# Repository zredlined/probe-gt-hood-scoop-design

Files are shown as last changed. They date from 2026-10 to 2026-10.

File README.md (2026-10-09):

# Probe GT hood scoop — #42

A bolt-on, 3D-printed fresh-air hood scoop for the 4OGS Ford Probe GT race car. It sits over a 199 x 75 mm opening cut in the hood ahead of the cone filter, feeds outside air down through a lined throat, and a short flap under the hood turns that air toward the filter. Black ASA, purple accents, 4OGS wordmark inlaid on the roof. Every part prints without supports.

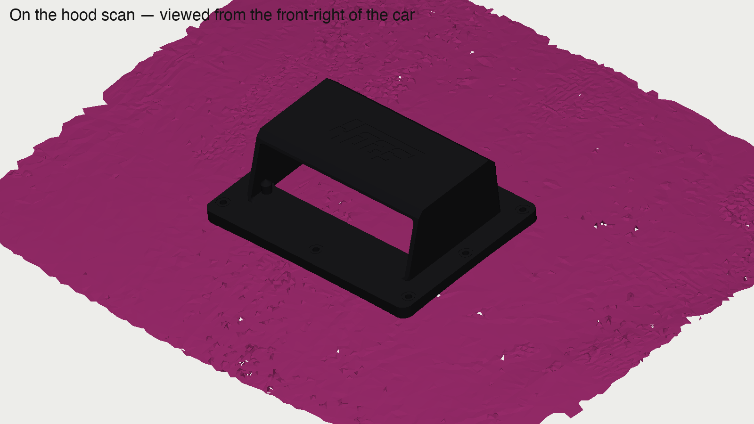
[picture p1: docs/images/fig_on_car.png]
On the hood


**Status: prototype, waiting for on-car checks.** The opening position, the hood's double-skin depth and the cone position all come from a 3D scan and a nozzle test, not from a tape measure. The first job is to print the template and confirm them. See the [build guide](docs/BUILD_GUIDE.md).

## What's here

| Folder | Contents |
|---|---|
| [`docs/BUILD_GUIDE.md`](docs/BUILD_GUIDE.md) | Step-by-step instructions with pictures. Start here. |
| [`docs/BOM.md`](docs/BOM.md) | Parts, hardware and filament. Only four things to buy. |
| [`docs/DESIGN.md`](docs/DESIGN.md) | How the design works, the coordinate frame, every parameter. |
| [`docs/DECISIONS.md`](docs/DECISIONS.md) | Why it is the way it is, newest first. |
| [`validation/`](validation/README.md) | What was checked against the scan and how the parts print. |
| [`stl/`](stl) | Printable parts, ready to slice. Local frame, millimetres. |
| [`step/`](step) | STEP export of the whole system for other CAD. |
| [`cad/`](cad) | Onshape FeatureScript (design master), the Python mirror that rebuilds the STLs without Onshape, and the validation and figure scripts. |
| [`reference/`](reference) | The scan meshes, the photos and the original design brief this was built from. |

## Parts at a glance

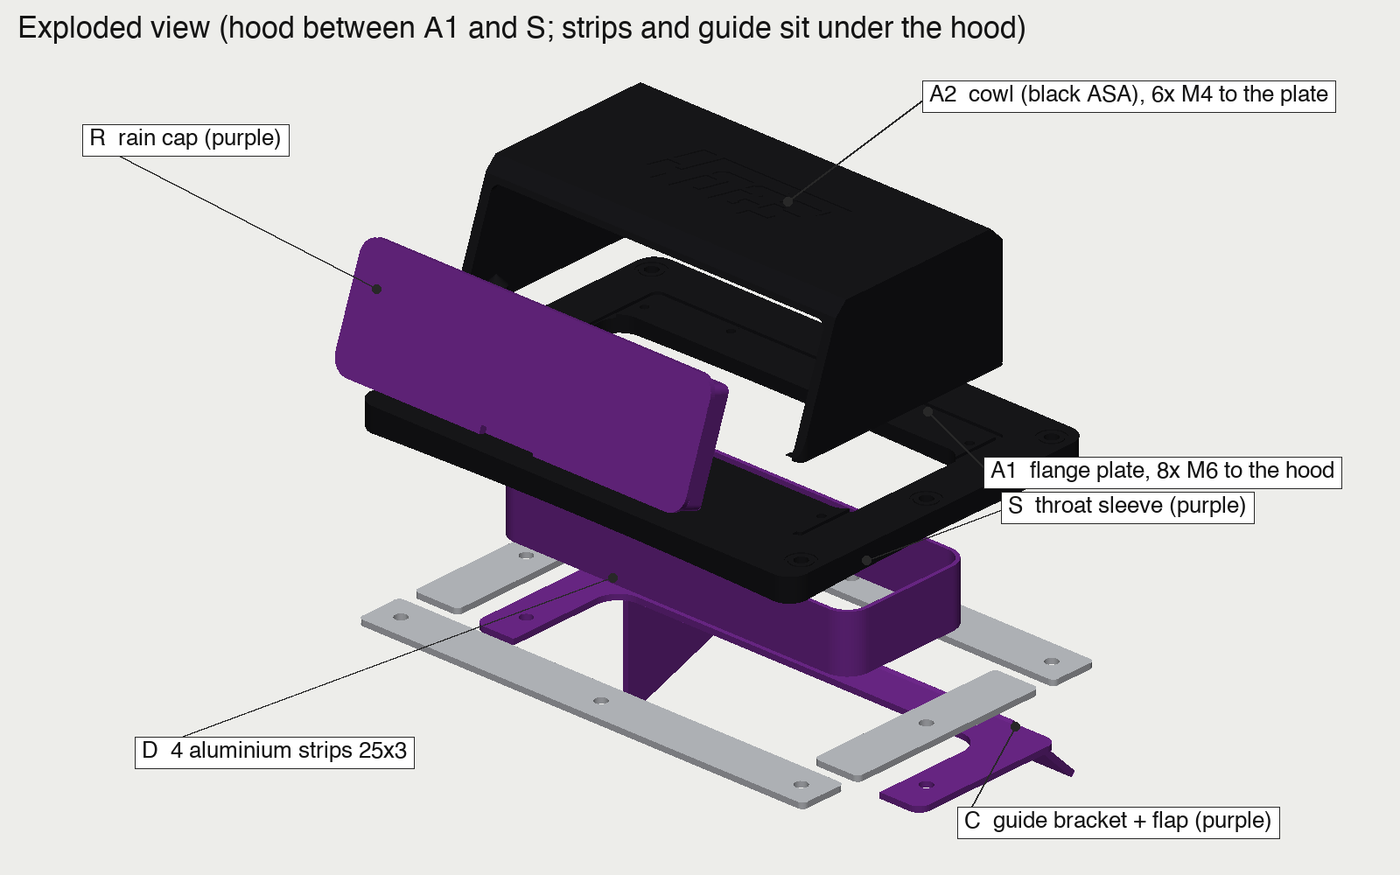
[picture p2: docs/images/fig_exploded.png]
Exploded


| Part | Material | Print | What it does |
|---|---|---|---|
| T  template | PLA | flat | Transfers the opening and the 8 bolt holes to the hood. Print this first. |
| A1 flange plate | black ASA | top face down | Matches the hood curve, carries the 8 M6 bolts, locates the cowl. |
| A2 cowl | black ASA (+ purple logo) | roof down | The slab with the raked mouth. Screws to the plate on the bench with 6 M4. |
| S  throat sleeve | purple ASA | standing | Lines the cut through both hood skins. |
| R  rain cap | purple ASA | flange down | Snap-in blank for rain or storage. |
| C  guide | purple ASA | bracket down | U-bracket plus 45° flap under the hood, aims air at the cone. |
| D  strips | 25 x 3 aluminium flat bar | cut and drill | Load-spreading backing for the 8 bolts. |

Hardware: 8 x M6x50, 6 x M4 self-tapping, nylocs, washers, Ø10 tube for limiters and spacers, 2 mm foam gasket tape.

## CAD

Design master: [Onshape document](https://cad.onshape.com/documents/b03b5bf08a93c5df66f722d9/w/0932d1534808bff872171f8f) (custom feature "Probe hood scoop system" in the "Probe scoop FeatureScript" tab; every dimension is a parameter). The scan meshes are in the same document in the scan frame, and the assembly "Scoop on car" shows the scoop on the hood.

To rebuild the STLs without Onshape:

```bash
pip install numpy trimesh shapely manifold3d networkx
python3 cad/local_build.py                      # writes stl/
python3 cad/local_build.py --set roofTop=76     # any parameter from DESIGN.md
```

The mirror was checked against the Onshape export of the same parameters: identical to within 0.13 mm.

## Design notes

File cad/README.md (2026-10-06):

# CAD sources

**Design master:** `scoop.fs`, an Onshape FeatureScript custom feature ("Probe hood scoop system"). It lives in the Onshape document's "Probe scoop FeatureScript" tab and is inserted into the Part Studio "Scoop system (placed on scan site)"; the "Scoop FLAT" studio holds the same feature laid flat for export. `scoop.fs` is generated by `gen_fs.py` (which injects the fitted hood-site frame from `site_fit.json`); edit the generator, not the .fs.

**Local mirror:** `local_build.py` rebuilds every printable STL from the same parameters without Onshape (numpy, trimesh, shapely, manifold3d, networkx). Verified against the Onshape export of the same parameters to 0.13 mm. Use it when the Onshape API quota is exhausted or when you just want parts.

```bash
pip install numpy trimesh shapely manifold3d networkx scipy matplotlib pillow rtree
python3 cad/local_build.py                       # -> stl/
python3 cad/validate.py                          # -> validation/ (needs reference/scan)
python3 cad/make_figures.py stl docs/images      # -> figures for the docs
```

**Onshape automation** (needs `ONSHAPE_ACCESS_KEY` / `ONSHAPE_SECRET_KEY` in the environment; every call counts against the account's API quota):
- `push_scoop.py '{"roofTop": 76}'` regenerates `scoop.fs`, pushes it, re-inserts the feature with all parameters (JSON overrides optional) and prints regeneration status.
- `assemble_export.py` rebuilds the "Scoop on car" assembly from the scan meshes plus the design studio, refreshes the flat studio, and exports STL/STEP.
- `mesh_scale.fs` is the tiny feature used to fix STL imports that Onshape read in metres.
- `os_api.py` holds the document IDs and auth helpers; `onshape_state.json` the element IDs created so far.

**Scan analysis:** `site_fit.py` fits the hood curvature at the opening site from `reference/scan/02_hood_outer_mm.stl` and writes `site_fit.json`. `raster.py` is a small z-buffer renderer used by the figure and check scripts.

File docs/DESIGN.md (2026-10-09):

# Design notes

## Intent
A supplemental fresh-air feed, not a sealed cold-air intake. The mouth faces forward on the hood's downslope, 74 mm up, well clear of the boundary layer. It captures far more air than the engine draws, so most of it spills into the bay and keeps the area around the cone filter slightly pressurised with outside air. A sealed airbox can bolt to the same opening and hole pattern later; the throat and bolt pattern were sized for that.

## Coordinate frame
Everything in the STLs is in a local frame on the hood at the opening centre O:
- **x** across the car, positive toward your right when standing at the bumper facing the car,
- **y** rearward toward the windshield,
- **z** out of the hood, zero at the outer skin surface at O. The plate underside follows the measured hood curvature (a quadratic fitted to the scan: 8.8° downslope toward the front, about 5 mm of sag at the plate corners).

In the scan's frame O is at about X 110, Y −340, Z 104. That came from the emissions-label neighbourhood the owner tested with a vacuum nozzle, not from a measurement, which is why the template exists.

## Parts and how they go together
Exploded

- **A1 flange plate**: 244 x 181 x 8, hood-matched underside, flat top. Eight Ø6.5 bolt holes with 0.6 mm debossed rings, a 1.5 mm seat for the sleeve, a 3 x 1.5 mm groove for the cowl tongue, six Ø4.3 countersunk holes for the cowl screws. Prints top-face-down with no supports.
- **A2 cowl**: 196 x 125 slab, roof at 74, mouth face raked back 20°, 4 mm brow chamfer, 10 mm tail chamfer, 4 mm corner radii. Mouth 186 x 55.5 (103 cm²) with a 2.5 mm inner lip radius. A 2.6 mm tongue on the skirt drops into the plate groove; six Ø10 bosses inside the skirt take M4 self-tapping screws (or captive M4 nylocs with `captiveNuts`). 4OGS wordmark debossed 0.6 mm on the roof for an AMS inlay. Prints roof-down with no supports.
- **S throat sleeve**: 199 x 75 outside, 2 mm wall, lines the cut through both skins so the cavity stays dry and the edges are hidden. Pushed up from below into the plate seat, sealed with RTV.
- **R rain cap**: flange matching the raked face, hollow 15 mm plug with 0.3 mm clearance, two 0.6 mm snap bumps, finger notch that doubles as a drain.
- **C guide**: U-bracket (two arms plus a rear bar) clamped under the side strips by the two middle bolts, with a 200 wide flap at 45° reaching 50 mm and a 55 mm inboard cheek that pushes air outboard toward the cone. Provisional until the clay test; reach, angle and cheek are parameters.
- **B bezel (optional)**: 5 mm purple frame flush in a recess on the raked face. Off by default; the AMS logo is the accent instead.
- **D strips**: four pieces of 25 x 3 aluminium flat bar under the inner panel. Two across (front and rear rows, 3 holes) and two short (middle bolts).
- **Fasteners**: 8 x M6x50 head-down, steel limiter tubes through the plate, steel spacer tubes across the inter-skin gap passing through Ø10.5 holes in the inner panel. The clamp path is head → strip → tube → outer skin → gasket → plate → nut, so no plastic carries preload and the inner panel is not pulled toward the outer skin. 6 x M4 join the cowl to the plate on the bench.

## Parameters
All in the Onshape feature and in `cad/local_build.py` (same names, mm).

| Group | Parameter | Default | Meaning |
|---|---|---|---|
| Opening | cutW, cutL, cutR | 195, 71, 10 | clear throat; hood cut = this + 2 x sleeveWall |
| | sleeveWall | 2 | |
| Hood stack | skinT, innerGap, innerT, gasketT | 0.8, 21, 0.8, 1.5 | **measure** innerGap at the pilot holes |
| Plate | baseW, baseFront, baseRear, baseR, baseT | 244, 97, 84, 10, 8 | |
| Cowl | bodyW, bodyFront, bodyRear, roofTop, wall, bodyR | 196, 65, 60, 74, 3, 4 | |
| | chamferF, chamferR, rakeDeg | 4, 10, 20 | |
| Mouth | mouthW, mouthR, lipR, bezelW | 186, 4, 2.5, 5 | mouth height = roofTop − chamferF − bezelW − gasketT − baseT (bezelW is the lintel band whether or not the bezel is built) |
| Cowl screws | bossD, bossH, screwPilot, screwClear, captiveNuts, nutAF, nutH | 10, 9, 3.4, 4.3, off, 7.2, 5.2 | six bosses at x ±91 y ±45 and x ±50 y 53 |
| Bolts | boltX, boltYF, boltYM, boltYR | 112, 80, −4, 72 | rows at y = −80, −4, +72; x = ±112 plus centre front/rear |
| | holeD, boltL, backingT | 6.5, 50, 3 | |
| Guide | guideW, guideReach, guideAngle, cheekH, guideT | 200, 50, 45, 55, 3 | physical-fit parameters |

## Design language
Teenage Engineering slab with a 90s scoop stance: flat top, crisp small chamfers, uniform radii, a raked mouth, exposed fasteners on a regular pitch, black body with a purple inlaid wordmark and purple functional parts. The car's livery is light blue and black with purple panels, hence purple.

## What is not proven
No CFD, no load test, no hood-closing sweep simulation. The scan's hood-underside registration is provisional (median 4 mm lateral, local conflicts) and the cone is not in the scan. The build guide's Round 1 exists to replace those assumptions with measurements. See [DECISIONS.md](DECISIONS.md) for why things are the way they are.

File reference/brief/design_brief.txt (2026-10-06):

ONSHAPE MCP BUILD PROMPT — PROBE HOOD SCOOP + BROAD AIR GUIDE
Revision 2026-10-05. Supersedes the MAX2509-specific handoff and earlier intake proposals.

TASK AND INTENT
Build actual editable parametric CAD in Onshape using your available MCP tools: an outside hood scoop, bolted mounting system, and removable broad air guide below the hood, delivering outside air toward the existing cone filter beside the battery. The owner may add shielding or an airbox later. The current configuration is an open fresh-air feed, with no promise that the cone will ingest only cold air.

IMPORTANT LATEST DECISION
DO NOT require a RIDGID nozzle, vacuum-hose connection, or 2.5-inch round restriction. The owner held a RIDGID MAX2509 under the hood and closed it to find a workable LOCATION and mouth FOOTPRINT. Preserve that packaging evidence; replace the nozzle with a broad printed guide. Its measured outside mouth was 195.2625 x 71.4375 mm. We deliberately adopt an approximately matching hood opening, now independent of the nozzle's unmeasured inside dimensions. Do not reproduce a vacuum nozzle or its snap fit.

PLACEMENT SOURCE OF TRUTH
The owner's attached underside screenshot contains a small white rectangle in an exposed light-colored rectangular region. Owner's clarification: stand facing the car and look at the underside of the raised hood; the box is just to the viewer's right, roughly aligned with the sticker visible in the scans. The physical nozzle test at that location allowed the hood to close. Treat that as the preferred location and approximate footprint, not as a calibrated global coordinate.
Do not move the opening elsewhere simply to fit the old concept. Do not reuse previous global X295/Y-70 or a 200 x 160 opening. Preserve the owner's viewing convention; underside and top views must not be silently mirrored. The screenshot does not establish an exact XYZ, orientation, or skin thickness. Do not invent millimeter measurements from its pixels or claim that gray scan regions prove absence of structure.

LOCAL DATUMS
Local O = center of the mouth footprint physically transferred to the hood at the tested location. Local X = long dimension across the car; local Y = rearward toward windshield; local Z = outward normal from hood. Mouth faces -Y, toward bumper. Confirm actual FRONT on the car; screen-up is not a vehicle datum. If the tested rectangle is yawed, expose opening_yaw separately from scoop_yaw and guide_yaw.
Before releasing a cutting drawing: place a 195 x 71 rounded-rectangle card in the tested position; trace the center and axes on masking tape. Check actual hood skins, reinforcement, bonded seams, and full hood closing sweep. Trial the complete flange/backing/nut/guide footprint, not just the hole. Record O relative to two identifiable physical hood features A and B (A-B, A-O, B-O and side of A-B, plus a third check dimension). Do not mix distances along curved sheet with projected CAD distances. After confirming the waste area, a small pilot hole inside that area can transfer the position to the outside; do not blindly drill through additional layers. Supply a photo or drawing identifying A and B. The sticker is a neighborhood identifier, not a precision datum.

PARAMETERS — MM, INITIAL DESIGN VALUES
cut_W = 195; cut_L = 71; cut_R = 10; center = O.
These are proposed cut dimensions based on the physically tested footprint, NOT measured existing hole dimensions. The guide mates to the new opening, so its external flange must be larger.
clear_mouth_W = 200; clear_mouth_H = 60; mouth_sill = 3 above local skin.
shell_wall = 3; main_flange_t = 5; flange_border = 20.
body_W = 210; body_front_Y = -65; body_rear_Y = +95.
base_W = 250; base_front_Y = -85; base_rear_Y = +115; total base footprint = 250 x 200.
Approximate scoop maximum height = 66 above local skin (3 sill + 60 clear + 3 roof), before curvature adaptation.
gasket_uncompressed_t = 2; compressed thickness per actual material.
metal_backing_t = 2 initial sheet-metal design value.
M5 fasteners; nominal clearance holes 5.5, finish-drilled.
All values are editable. Mark measured inputs separately from initial design assumptions.

UPPER SCOOP
Build a forward-facing hollow raised scoop. Smooth entrance lip, starting internal radius about 3 mm. Inner roof approximately 63 above local hood from Y=-65 through Y=+40, keeping the full downward passage over the aperture, whose aft edge is Y=+35.5. Smoothly close the tail by Y=+95; expose tail length as a parameter so it can be extended if room and printing allow. This short tail is a packaging choice, not an optimized low-drag aerodynamic profile. No rear-facing opening. No obstruction or decorative web across the throat.
The hood may form the floor outside the hole if the perimeter seal is continuous. Fit the flange to a smooth representation of the actual local outer hood curvature, or use a replaceable contoured adapter and gasket. Do not force a flat warped part down with bolt torque. Do not reuse the old hood curvature polynomial from a different location. Avoid converting the full scan mesh into thousands of CAD faces.

LOWER AIR GUIDE — DEFAULT OPEN CONFIGURATION
Use a removable broad chute/deflector connected to the underside mounting assembly. It moves with the hood. Its inlet follows the rounded 195 x 71 opening; use a radiused entry and no smaller hose neck. Start with two side cheeks and a smooth turning wall that redirects downward flow toward the exposed filter media. The outlet and underside remain open where needed for clearance, engine movement and drainage. Keep clear of the cone's solid end cap and avoid pressing against the filter.
Guide depth, guide reach, guide yaw, turn angle, outlet width, outlet height, and engine/filter clearances are physical-fit parameters, NOT dimensions inferred from the nozzle mouth. If the scan cannot establish them, create an adjustable/shallow fit-check version and a hinge/slot or interchangeable guide geometry, explicitly labeled provisional. Do not invent a full nozzle depth from the 71 mm mouth length.
Allow a 25-50 mm outlet-to-filter gap as a starting packaging target only where measured motion permits. Check all hood sweep positions and engine movement. Use broad radii and no unnecessary corrugated hose. Air can spill from this open guide; it is a practical supplemental cooling feed, not a pressure-sealed intake.

OPTIONAL LATER CLOSED CONFIGURATION
Provide an optional enclosed wide duct or airbox interface with the same hood opening and fastener pattern. Target a minimum clear cross-sectional area of 100-110 cm2; prefer about 120-135 cm2 where packaging allows. Evaluate areas in sections normal to the local flow path, not just plan-view widths. The rounded 195 x 71 cut is approximately 137.6 cm2; 200 x 60 mouth is 120 cm2 before mesh. If adding mesh, keep high open area and adjust dimensions so it does not become the smallest restrictive section; record open-area assumptions. Do not reduce the system to a 63.5 mm bore (~31.7 cm2). A later sealed airbox requires pressure/temperature testing; these geometry targets do not prove sufficient pressure recovery or flow.

HOOD FASTENING AND BACKING
Use eight M5 through-bolts, metal washers/clamp strips, metal compression limiters, positive locking nuts suitable for actual temperature, and a conforming metal underside load-spreading frame or strips. Initial local hole centers:
(-115,-75), (+115,-75), (-115,0), (+115,0), (-115,+105), (+115,+105), (0,-75), (0,+105).
Positions are parameters, to be moved if ribs/tool clearance require. Keep appropriate edge distance and distributed retention. Initial nominal hole-center distance from outer flange edge is 10 mm. Show washer diameters and tool-access envelopes. Put mounting bolts outside the airflow chamber.
Stack: bolt head -> metal washer/clamp strip -> printed flange with compression limiter -> weather gasket -> hood sheet -> metal backing -> washer -> locking nut.
A compression limiter must bear on metal across the relevant compressible stack; a sleeve floating inside plastic does not solve creep. Derive sleeve and bolt lengths from measured installed stack and specified gasket compression. Do not assign a generic tightening torque to crush thin sheet or plastic. Do not pull two separated hood skins together with bolt preload: move the hole or provide fitted spacers across a measured gap. Do not drill/cut reinforcement without a separate assessment; prefer keeping the owner's hole location and adapting flange/backing details.
All primary scoop retention must be through-bolted and metal-backed. No reliance on self-tappers, adhesive tape, printed screw threads, or heat-set inserts alone. The lower guide attaches independently to metal-backed captive hardware and can be removed without dismantling the upper scoop. Keep retention hardware captive or outside the airflow; nothing loose above the cone. Provide access for assembly and maintenance.

HEAT, PRINTING, WATER
ASA is a candidate for the exterior scoop, subject to the exact filament datasheet, actual surface temperature and print quality. Do not treat a published softening point as allowable sustained clamped temperature. Under-hood guide material needs its own heat assessment; allow a formed-metal guide using the same mounts if measured conditions exceed the printed material's capability. No unqualified approval of PLA. Printed parts need generous fillets, local flange gussets, sufficient perimeters and solid fastener zones; specify actual slicer wall results. Check warping, support removal and the printer's usable build area for a 250 mm-wide flange. If splitting, use a mechanically supported joint away from critical throat/fastener regions, not a thin glued butt seam.
Include an installed-low-point drainage path away from filter and electrical parts; keep rain from being deliberately dumped onto the cone. Offer a removable broad splash deflector if needed, without choking flow. The scoop is not rain-proof. Preserve the proper engine air filter.

ONSHAPE WORKFLOW / DELIVERABLES
Build named, editable variables, sketches, surfaces and solids using the available MCP tools. Work on the prototype while unknowns stay explicit. Do not stop at a prose design plan.
1. A small fit-check template/flat ring FIRST, showing 195 x 71 opening, R10 corners, center/axes, flange and backing envelopes. Use it to transfer physical position and check mounting access before cutting or printing the entire scoop.
2. Parametric upper scoop, contour adapter if required, removable open lower guide, and optional future closed-duct interface in separate parts/configurations.
3. Metal backing and retainer parts, sleeves, washers and fasteners modeled separately; hardware BOM with lengths calculated from measured stack.
4. Full-size cut/drill template with FRONT, O, physical A/B datums, cut contour, hole centers, and a 100 mm calibration line. Label PRELIMINARY until actual placement, skins, mounting and swept clearances are verified. A planar projection is not automatically a developed pattern for a curved hood; state the method and verify on the car.
5. Dimensioned top/side/section and exploded assembly views. Explicit installed assembly order. STL/3MF for printable parts, STEP for CAD exchange, DXF for backing and templates.
6. Check regeneration, wall thickness, watertight printable solids, assembly/tool access, continuous upper seal, broad airflow path and hood/engine swept clearance. State which checks were actually performed. Do not claim CFD, tested strength, exact scan placement, successful tool operations or physical fit without evidence.
7. Supply a short physical commissioning plan: inspect retention and hot-soak deformation, verify hood latch/closing clearance, check rain drainage, and compare intake temperature under comparable driving. If a sealed box is later added, include intake pressure-drop measurement at high engine demand.

REFERENCE FILES INCLUDED IN THIS PACKAGE (paths relative to this prompt)
../02_scan_reference/01_engine_bay_mm.stl
../02_scan_reference/02_hood_outer_mm.stl
../02_scan_reference/03_hood_underside_PROVISIONAL_mm.stl
Import in mm at shared origin. Global +Y approximately rearward, +Z up. The underside alignment has unresolved conflicts; it does not certify rib/part clearances. The cone is absent from the scan. If files are unavailable to your session, request them; do not pretend to have read them. Use the attached marked screenshot and owner's physical test to resolve location. Do not let obsolete earlier placement parameters override the latest user instruction.

TECHNICAL BASIS / REFERENCES
Area checks above are elementary geometry, not a CFD simulation. At assumed 0.16 m3/s engine demand a hypothetical actual 63.5 mm-ID tube has ~50.5 m/s mean velocity, versus ~11.6 m/s through the proposed hood aperture; actual captured flow and losses are unknown. This motivates eliminating the narrow vacuum fitting, not a promised performance gain.
ASA material guidance: https://help.prusa3d.com/article/asa_1809
RIDGID model identification only: https://www.ridgid.com/us/en/max2509

PACKAGE PHOTO REFERENCES (relative to this prompt)
../03_photos/01_user_marked_hood_underside.png — latest owner-selected location, white rectangle.
../03_photos/02_engine_bay_with_cone_filter.png — installed intake/filter context, absent from scan.
The folder 02_scan_reference contains historical scan documentation. Its geometric caveats remain relevant; the current brief controls design intent.

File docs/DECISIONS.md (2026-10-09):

# Decisions

Why the design is the way it is. Newest first. Each entry is the decision, the reason, and what it replaced.

## 2026-10-08 — Rev H

**Two-piece body, joined on the bench.** A flange plate printed top-face-down and a cowl printed roof-down, both with zero supports. Six M4 screws go up through countersunk holes in the plate into bosses inside the cowl skirt, with a tongue-and-groove to locate them. Replaces the one-piece body, which needed a full ring of support under the flange at 60 mm and put support scars on the visible nut face. Also fixes a gap in the earlier two-piece attempt, which had no fastener between cowl and base. Self-tapping M4 is the default; a parameter switches the bosses to captive M4 nyloc pockets.

**Mouth face raked 20°.** The front face leans back instead of standing vertical. Less bluff, throws rain down rather than into the throat, and it is the most recognisable 90s scoop cue (WRX, Evo, GTi-R all had raked boxes). Roof raised 72 → 74 to keep the mouth above 100 cm² (now 186 x 55.5, 103 cm²).

**AMS for the logo, not the bezel.** The 4OGS deboss on the roof becomes a purple inlay with three filament swaps in the first layers, which costs almost nothing. A full-height purple bezel would swap on every layer and purge 150–300 g of filament for a 3 g feature, so the bezel is now an optional separate part, off by default.

**Scan meshes re-registered in Onshape.** The STL import had centred each mesh on the origin; the scoop therefore appeared displaced toward the middle of the hood in the assembly. The unit-fix feature now also moves each mesh back by its original bounding-box centre. The local renders and validation were never affected; they always used the raw scan files.

## 2026-10-06 — Rev F / G

**Bolts head-down, nylocs on top.** With nuts underneath, the bolt ends came within 2 mm of engine-bay structure at the front-right corner, where the scan shows only about 43 mm under the skin. Heads down removes 10 mm of under-hood protrusion.

**Guide clamped by the two middle bolts.** A U-bracket with the flap replaced a hanger ring with rivnuts, bosses and four M6x20. Removes four purchases and a tool; the guide comes off by loosening two nuts.

**Four pieces of 25 x 3 flat bar instead of a sheet frame.** Hardware-store material, hacksaw and drill.

**Cowl narrowed 210 → 196.** A 10 mm socket on the side nuts needed 8.5 mm of radius and had 7. Now 14 mm centre-to-wall.

**Spacer tubes through an oversize hole in the inner panel.** The hood is double-skinned at the site (about 21 mm, varying). The tube bears on a washer against the outer skin and the inner panel is never clamped, so the depth at each hole only changes a tube length.

## 2026-10-05 — Rev A to E

**Location.** The owner's nozzle-tested spot on the exposed label patch, not a position inferred from the scan. The scan was used to find the site (label colours), fit the hood curvature there, and check clearances.

**Hardware M6.** The brief said M5; the owner has M6x50 in quantity.

**Throat sleeve.** The hood cut grows to 199 x 75 so a 2 mm liner can run through both skins, keeping the cavity dry and hiding cut edges.

**Open fresh-air feed, not a sealed intake.** Per the brief. The throat and bolt pattern are sized so a sealed box can be added later on the same opening.

**Teenage Engineering slab, black with purple accents.** Flat roof, small chamfers, uniform radii, exposed fasteners on a regular pitch, debossed wordmark. Colours follow the car's livery.

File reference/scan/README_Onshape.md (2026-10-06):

# Probe engine bay and hood — Onshape reference, first pass

Import the STL files as **millimeters**. All share one coordinate system. Z points approximately up, Y approximately rearward and X across the car. The frame comes from the bay scan, not a surveyed vehicle centerline or ground plane. Keep the supplied origin and orientation; do not center or rotate individual meshes independently.

## Start with these files

- **01_engine_bay_mm.stl** — 250,000 triangles, about 12.5 MB. Engine bay with its captured surrounding panels.
- **02_hood_outer_mm.stl** — about 100,000 triangles, 5 MB. Isolated outer hood, positioned from the closed-hood exterior scan through overlapping bodywork.
- **03_hood_underside_PROVISIONAL_mm.stl** — about 150,000 triangles, 7.5 MB. Approximate closed-position underside. This placement has unresolved local conflicts and is not approved for tight clearance decisions.
- **04_combined_LAYOUT_ONLY_PROVISIONAL_mm.stl** — all three, about 500,000 triangles, 25 MB. One-file convenience reference. Includes the provisional underside. It is a concatenation of open mesh surfaces, not a welded or watertight solid; separate component names and convenient visibility controls are not guaranteed in an STL import.
- Matching **color PLY** files — for color inspection in CloudCompare or other mesh tools; use STL for this Onshape workflow.

These are reference meshes, not printable parts. Use them to locate and shape new parametric CAD parts. Scanned openings and missing coverage remain open. A missing surface does not establish free space.

## Onshape setup

1. Unzip the package. Create an Onshape document and import the three numbered individual STL files, choosing **millimeter** units. Leave any Y-up to Z-up reorientation off: these files are already approximately Z-up.
2. Keep the imports as separate references so the outer hood and underside can be hidden independently. If imports appear in separate Part Studios, use a design Part Studio with Derived references at **Base origin**, without additional placement. If the mesh selection is inconvenient in your import, the combined STL provides a one-file layout alternative.
3. Check scale against these approximate envelopes: engine-bay mesh 1630 × 1439 × 539 mm; isolated hood outer 1487 × 1389 × 114 mm. These are bounding boxes of the captured geometry, not nominal factory part dimensions.
4. Begin with the engine bay and outer hood. Enable the provisional underside only when reviewing its uncertainty. Model the vent and duct as normal CAD features, using local sections/reference sketches where needed. Avoid converting every mesh triangle into an individual CAD face.
5. Before fixing a close-fitting duct, validate the underside position with physical measurements or an additional scan that provides a stronger geometric connection. Check the front headlight notches, both rear corners, and several inner-reinforcement heights.

The exports were read back locally and checked. They have **not** been imported into the user's Onshape account during this task.

## What is established

The saved EXStar clouds were extracted with their normals and captured colors. Original EXStar projects were not changed. The hood-closed exterior and hood-open engine bay were aligned by a rigid, unit-scale geometry fit using common painted bodywork. No matching marker constellation was found between those projects; the underside has no saved marker set.

Five overlapping body regions were checked after fitting. Median nearest-point differences were about **0.54–1.05 mm**, with 95th-percentile differences **1.04–1.64 mm** among accepted local correspondences. These are agreement between scans, not certified physical accuracy. Checks use geometric correspondence and normal agreement; unmatched/uncaptured regions are excluded and counts are in the JSON report.

The outer hood was separated by identifying exterior surfaces absent from the hood-open scan and selecting the connected hood footprint. This is a scan-derived segmentation, not an exact factory trim boundary. Shared-body subtraction can trim a few millimeters near the panel gaps; small segmentation imperfections remain.

## What remains provisional

The underside was rigidly fitted using painted perimeter strips and the isolated outer-hood silhouette, including the headlight notches and curved rear edge. No scaling, nonrigid warping, or forced surface fusion was used. A folded underside edge is not the same physical surface as the top skin.

The final fit used 1,691 perimeter samples after excluding 247 likely background/nonmatching samples from the fit. Median lateral edge disagreement is **4.41 mm**, and the 95th percentile is **12.32 mm**. Median absolute vertical edge disagreement is **1.27 mm**, with a 95th percentile of **3.98 mm**. These fitted-edge statistics do not establish interior accuracy.

A separate raw-point height check found unresolved intersections: among interior underside samples with nearby outer-skin support, about **6.8% lie more than 2 mm above the outer skin**, and **2.9% more than 5 mm above**. This diagnostic includes all captured underside geometry in the tested footprint; it does not establish the cause. The underside is therefore useful for reviewing the rough layout, but **do not trust it as a collision envelope yet**. The cross-section image shows the mismatch. A tight duct design should wait for these conflicts to be reconciled.

Three disconnected wiper/background fragments were removed from the Onshape underside mesh after component inspection. The full extracted cloud and detailed meshes preserve them for review. Other small captured parts were retained where possible.

## Mesh processing and validation

CloudCompare performed spatial subsampling at 2 mm for the bay/exterior and 1.5 mm for the underside. Open3D performed ball-pivoting reconstruction and quadratic simplification. No global watertight reconstruction, blanket hole filling, or surface smoothing was used.

The final CAD copies total about 500,000 triangles. Bidirectional sampled comparisons against the detailed reconstructed meshes give 95th-percentile simplification differences below **0.30 mm** for all three. This isolates the extra change caused by simplification: it does not include scan error, alignment error, missing coverage, or reconstruction error. Larger local maxima are recorded in the report.

The full native-color clouds, aligned clouds, detailed meshes, transform matrices, scripts and logs remain in the parent work folder. The separate Blender review file preserves three named objects at the supplied positions. The exploded illustration temporarily offsets the hood layers for visibility; the STL files and saved Blender objects have no exploded offset.

## Official Onshape references

- [Importing files and STL units](https://cad.onshape.com/help/Content/Document/importing_files.htm)
- [Mixed modeling with mesh references](https://cad.onshape.com/help/Content/PartStudio/mixed_modeling.htm)
- [Derived and base-origin placement](https://cad.onshape.com/help/Content/PartStudio/derived.htm)

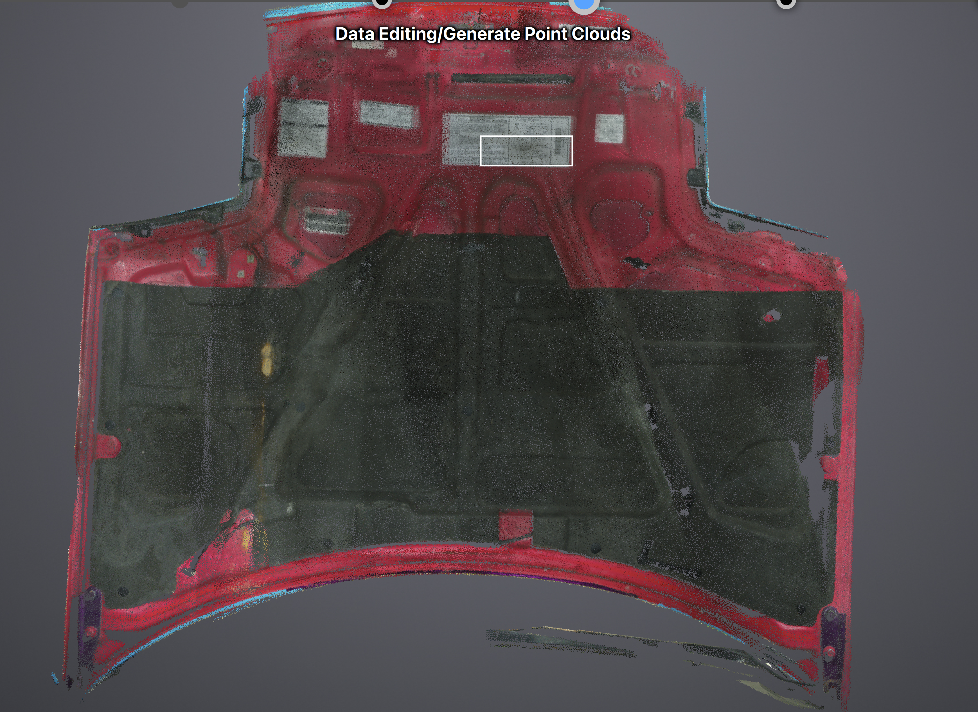
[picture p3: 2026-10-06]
reference/photos/01_user_marked_hood_underside.png

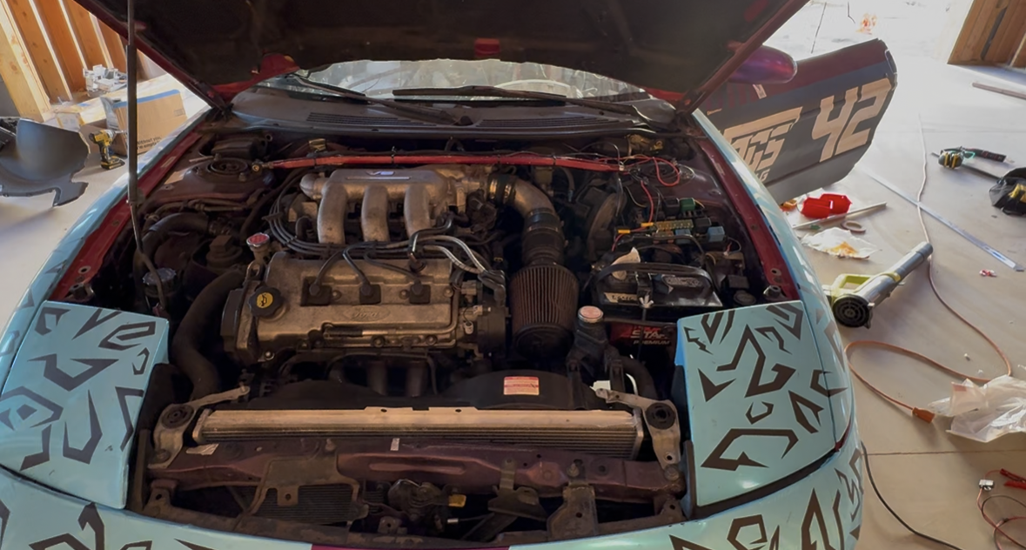
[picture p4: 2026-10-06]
reference/photos/02_engine_bay_with_cone_filter.png

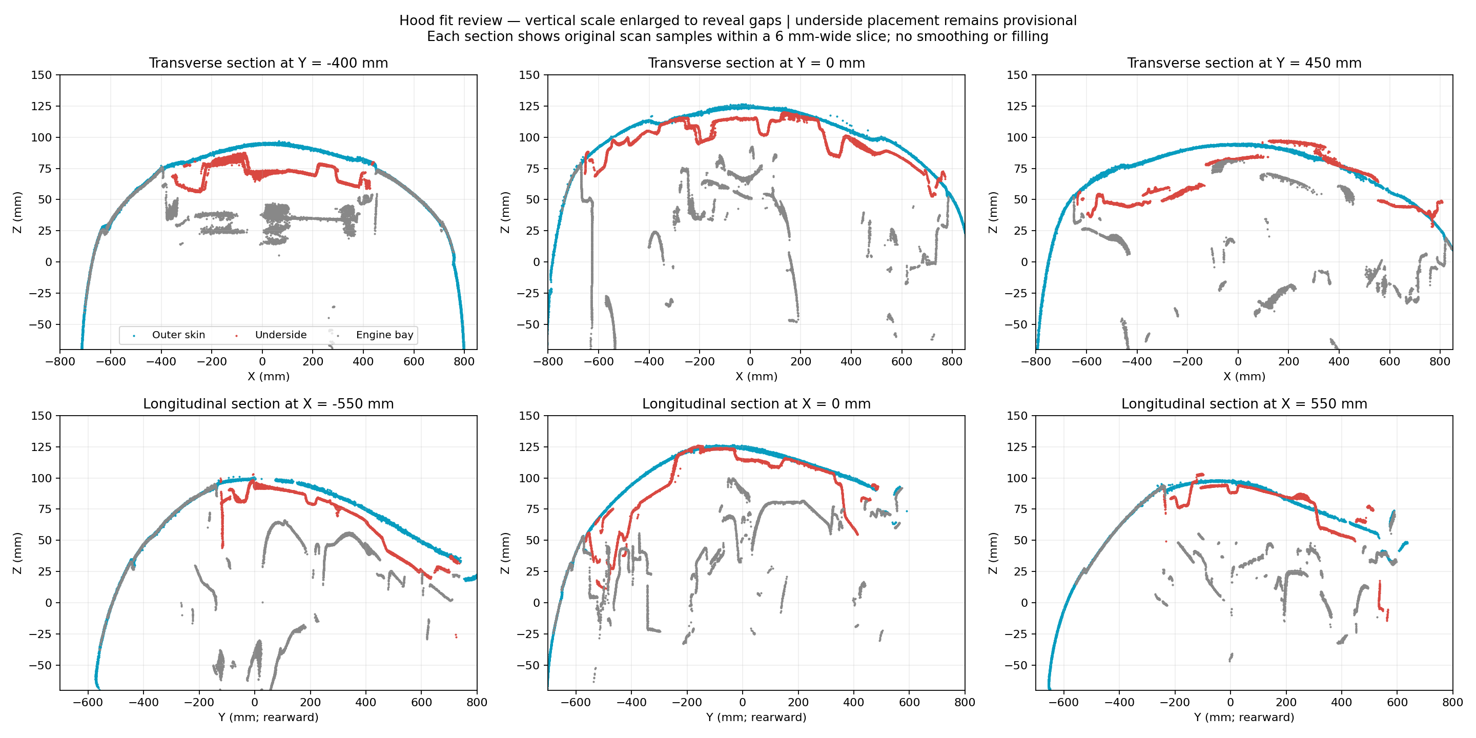
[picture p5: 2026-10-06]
reference/scan/05_raw_scan_sections.png

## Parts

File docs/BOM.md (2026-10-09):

# Bill of materials

Depths marked **measure** are confirmed in Round 1 of the build guide before anything is cut to length.

## Printed parts

| Part | File | Material | Orientation | Supports | Walls / infill | Filament |
|---|---|---|---|---|---|---|
| T  template | `stl/T_fit_check_template.stl` | PLA | flat | none | 2 / 15 % | ~40 g |
| A1 flange plate | `stl/A1_flange_plate.stl` | ASA, black | top face down (curved side up) | none | 4 / 15 % | ~150 g |
| A2 cowl | `stl/A2_cowl.stl` | ASA, black (+ purple for the logo, see below) | roof down | none | 4 / 30 % | ~95 g |
| S  throat sleeve | `stl/S_throat_sleeve.stl` | ASA, purple | standing | none | 3 / any | ~21 g |
| R  rain cap | `stl/R_rain_cap.stl` | ASA, purple | flange down, plug up | none | 3 / 20 % | ~55 g |
| C  guide | `stl/C_guide_flap.stl` | ASA, purple | bracket down | none (45° flap) | 4 / 30 % | ~41 g |
| B  bezel (optional) | build with `--set buildBezel=1` | ASA, purple | on its back | none | 3 / 100 % | ~3 g |

Totals: black ASA about 245 g, purple ASA about 120 g, PLA about 40 g. Estimates, allow 25 %. Nothing needs supports.

**Logo inlay with the AMS:** the cowl prints roof-down, so the 0.6 mm 4OGS deboss is in layers 1–3. Assign those layers (or a modifier on the deboss) to purple. Three swaps total. Do not multi-colour anything taller; a full-height purple bezel would purge more filament than the whole part weighs.

### Why these materials
- **ASA** for every part on or under the hood. The skin reaches 70–90 °C in sun with a hot engine; ASA stays stiff to about 95 °C and does not chalk in UV. Door closed, nozzle 260–270 °C, bed 90–100 °C, aux fan off, part fan low, dry filament, glue stick on the textured plate, 5 mm brim on the plate.
- **PLA** for the template only (softens above ~55 °C).
- **PETG** is not recommended on the hood (softens 75–80 °C). Fine for a throwaway first-fit guide.
- If the guide droops after a hot run, print it again in PC or PA-CF from the same file.

## Hardware

| Item | Qty | Spec | Notes |
|---|---|---|---|
| M6 x 50 button head (ISO 7380) | 8 | 8.8 or stainless | On hand. Head goes under the strip, nyloc on top. |
| M6 nyloc nut | 8 | DIN 985 | On top of the plate. |
| M6 flat washer Ø12 | 16 | DIN 125 | 8 under the nuts, 8 between spacer tube and outer skin. |
| M4 x 16–20 self-tapping screw, countersunk | 6 | for plastic | On hand. Cowl to plate, fitted on the bench. (Or M4 x 16 machine screws with M4 nylocs in the bosses: build with `--set captiveNuts=1`.) |
| Aluminium flat bar 25 x 3 mm | 1 m | 6061 or 6082 | 2 x 249 mm with three Ø6.5 holes, 2 x 110 mm with one hole. |
| Tube Ø10 outside, 1.5 wall | 1 m | aluminium or steel | 8 limiters at **8.0 mm** (plate thickness), 8 spacers at the **measured** depth minus 2.4 mm. |
| Closed-cell foam tape 2 mm x 20–25 mm | 1.5 m | EPDM or neoprene, adhesive | Gasket loop under the plate and around the throat. |
| RTV silicone or seam sealer | 1 tube | black | Sleeve to inner panel. |
| Rust primer or touch-up paint | 1 | | Cut edges and holes. |
| M6 acorn nut | 8 | DIN 1587 | Optional. Covers the ~7 mm of thread above the nyloc; otherwise trim. |

New purchases: the flat bar, the tube, the foam tape, and nylocs if there are none in the bin.

## Tools
Drills 3, 6.5 and 10.5 mm (or a step drill), Ø24 hole saw or step drill for the corners, jigsaw with a fine metal blade or a nibbler, files, deburring tool, hacksaw or cut-off wheel, depth gauge or hooked wire plus ruler, masking tape, torque wrench to 6 N·m, 10 mm socket, 4 mm hex key, PH2 or T20 driver for the M4s.

## Bolt stack
Head below the strip, nut on top. From the bottom: button head 3.3 → strip 3 → spacer tube (measured, through a Ø10.5 hole in the inner panel) → washer 1.6 → outer skin 0.8 → gasket 1.5 compressed → plate 8 with a steel limiter tube inside → washer 1.6 → nyloc 6. At the scan's 21 mm gap that is 42.7 mm head-to-nut, leaving about 7 mm of M6x50 above the nut. If a measured depth exceeds about 32 mm, that hole needs an M6x60.

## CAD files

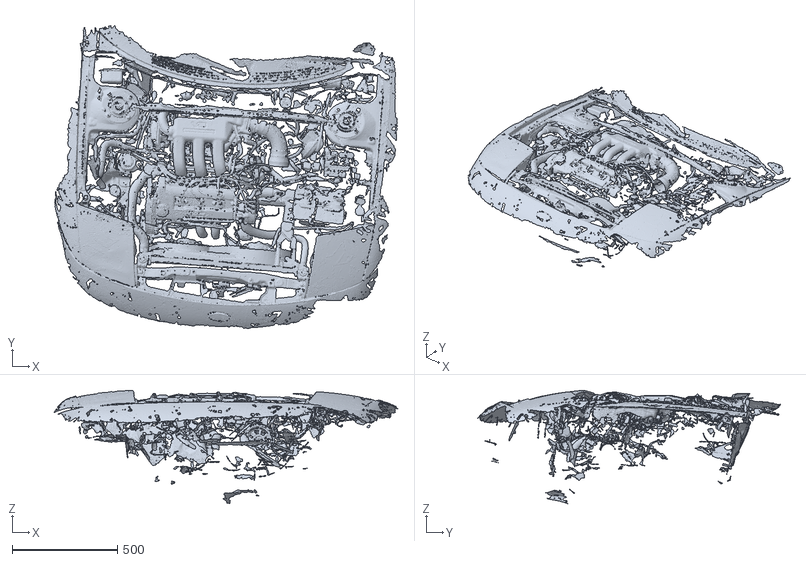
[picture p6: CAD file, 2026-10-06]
reference/scan/01_engine_bay_mm.stl
1630.3 x 1439.5 x 538.7

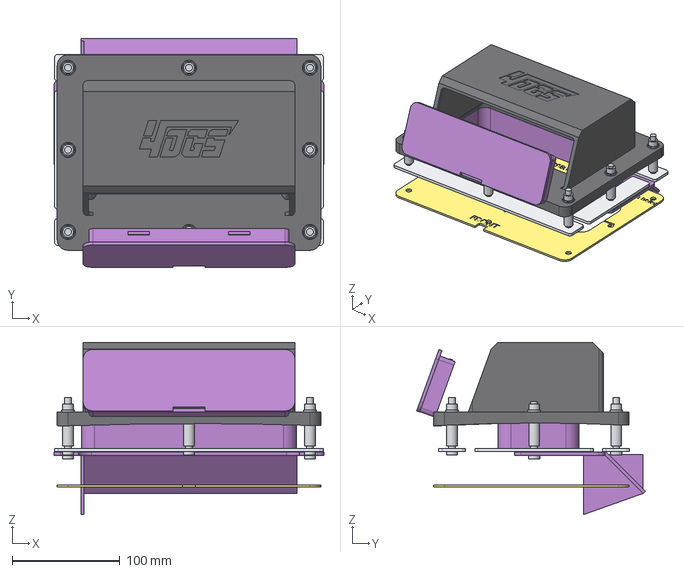
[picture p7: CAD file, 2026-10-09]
step/probe_hood_scoop_system.step
250.0 x 211.8 x 159.6 mm

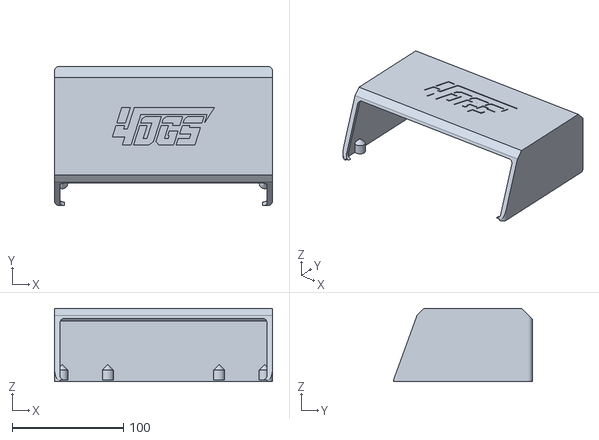
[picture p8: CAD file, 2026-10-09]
stl/A2_cowl.stl
196.0 x 125.0 x 66.0

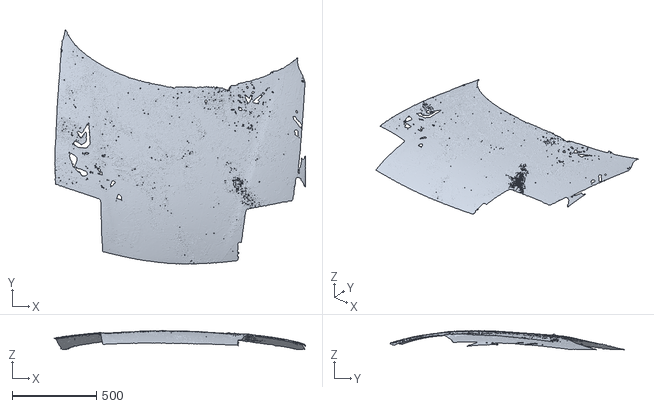
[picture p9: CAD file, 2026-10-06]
reference/scan/02_hood_outer_mm.stl
1487.4 x 1388.8 x 114.1

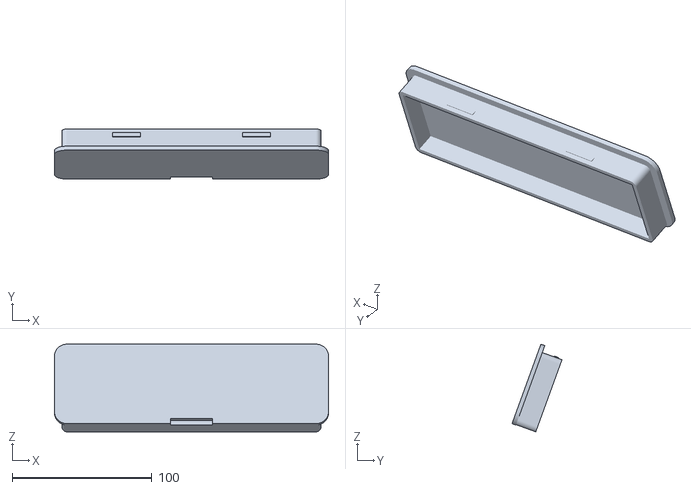
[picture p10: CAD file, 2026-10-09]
stl/R_rain_cap.stl
196.0 x 35.8 x 62.7

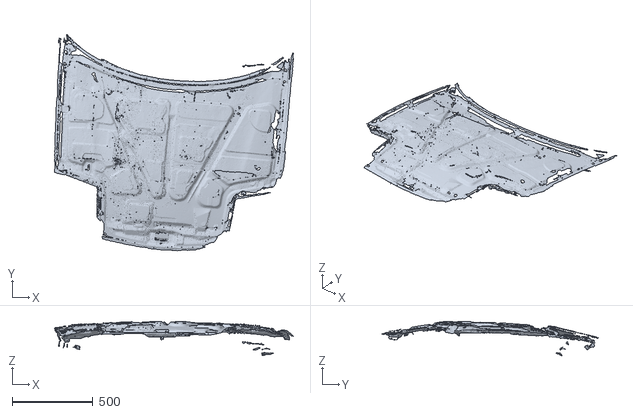
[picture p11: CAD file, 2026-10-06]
reference/scan/03_hood_underside_PROVISIONAL_mm.stl
1479.3 x 1340.9 x 212.5

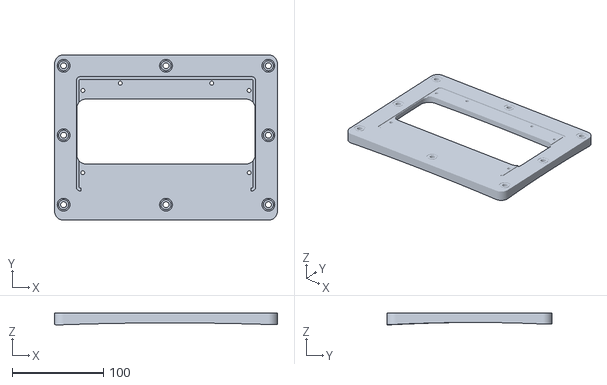
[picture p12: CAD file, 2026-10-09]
stl/A1_flange_plate.stl
244.0 x 181.0 x 12.8

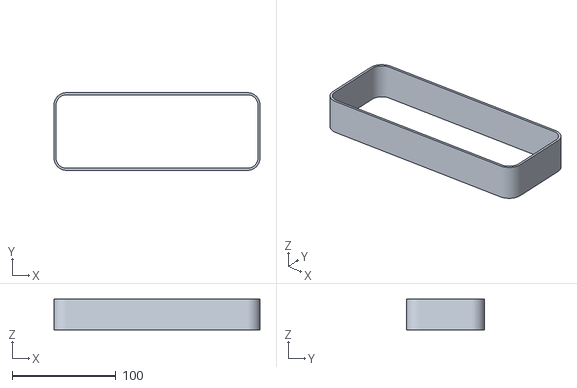
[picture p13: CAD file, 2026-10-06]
stl/S_throat_sleeve.stl
199.0 x 75.0 x 29.9

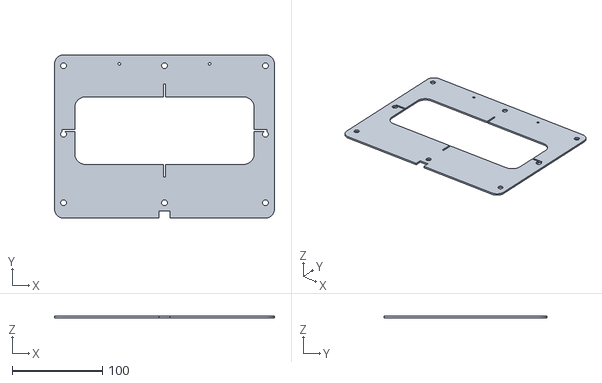
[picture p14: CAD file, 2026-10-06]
stl/T_fit_check_template.stl
244.0 x 181.0 x 2.00

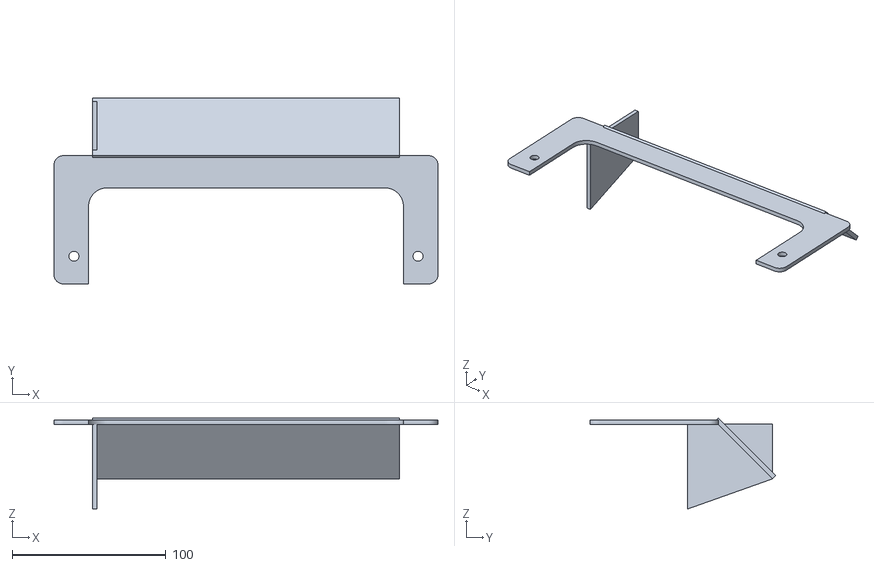
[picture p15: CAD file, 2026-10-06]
stl/C_guide_flap.stl
250.0 x 121.0 x 59.2

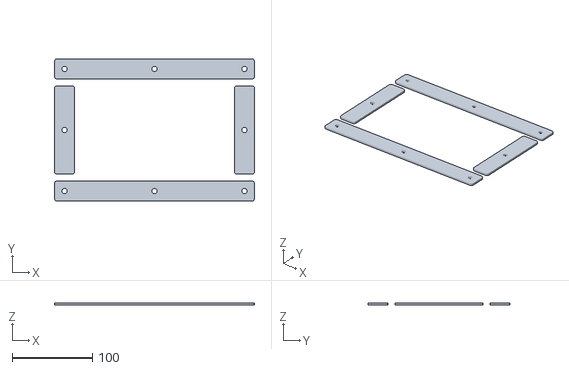
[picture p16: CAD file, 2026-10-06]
stl/D_backing_strips_reference.stl
249.0 x 177.0 x 3.00

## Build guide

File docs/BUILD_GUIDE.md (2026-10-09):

# Build guide

This is written for whoever is at the car. Everything is in millimetres. "Front" always means toward the bumper, and "right" means your right when you stand at the bumper facing the car.

There are two rounds. **Round 1** is the template and a few measurements. Send those back and the design gets updated (bolt lengths and tube lengths depend on them). **Round 2** is the actual cut and fit.

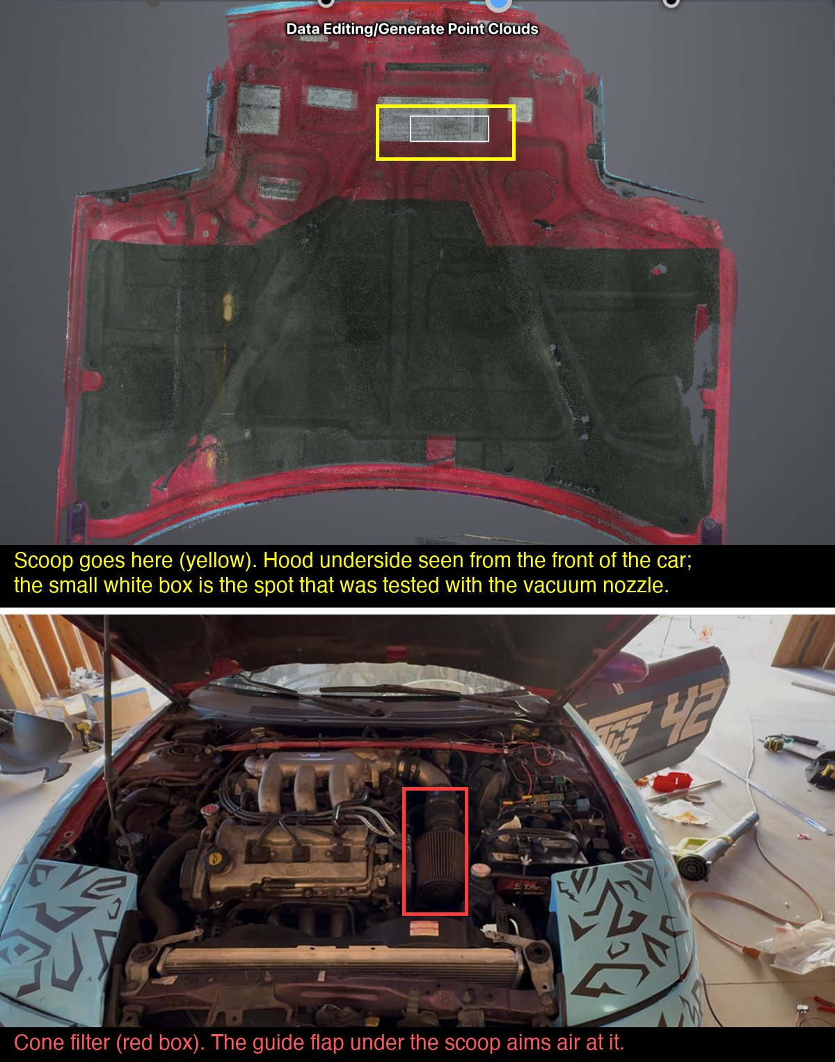
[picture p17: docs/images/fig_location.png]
Where it goes


---

## Round 1 — check the spot (an hour, no cutting)

### What you need
- The template, printed: `stl/T_fit_check_template.stl`, PLA, flat on the bed, 0.2 mm layers. Check it after printing: the two small holes near the back edge must be exactly 100 mm apart.
- Masking tape, a marker, a 3 mm drill, a depth gauge or a stiff piece of wire and a ruler, a phone for photos.

### 1. Put the template on the hood
Hood up. Hold the template against the **underside** of the hood on the bare metal patch with the emissions stickers, to the right of centre. The small triangle notch points to the **front** (bumper). Line the centre cross up with the spot that was tested with the vacuum nozzle.

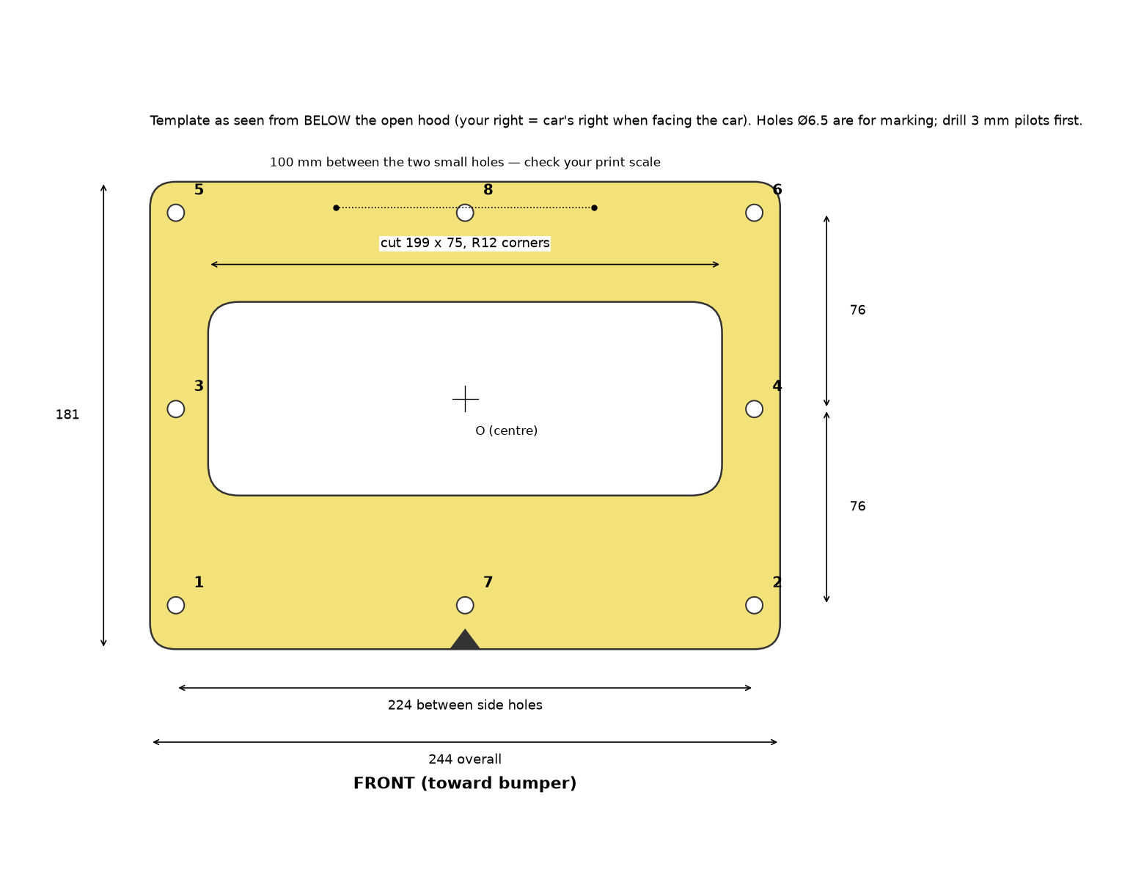
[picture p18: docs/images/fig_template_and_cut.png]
Template


Look for:
- The whole template lies on flat metal. No hole should land on a raised rib or on the black insulation pad. If one does, slide the template a little and tell us how far.
- Nothing above the template inside the engine bay would be hit by a box 70 mm tall sitting where the template is. If you have a 70 mm block, set it on the patch and close the hood slowly. It should close with room to spare.

Tape the template down. Mark through all 8 holes and draw around the inside of the big opening. Write the hole numbers next to the marks (they are on the drawing above).

### 2. Pick two landmarks
Pick two things on the hood underside that will not move, for example a weld nut and a rib corner. Call them A and B. Measure A to B, A to the template centre, and B to the template centre. Take a photo showing A, B and the template. This lets us put the template back in exactly the same place later.

### 3. Drill eight 3 mm pilot holes
Through each of the 8 marks, drill straight through the hood. You will go through two layers of metal: the inner panel and then the outer skin. Go slowly at the end so the drill does not wander on the paint.

### 4. Measure the depth at each hole
At each pilot hole, measure from the **top of the paint** down to the **underside of the inner panel**. A depth gauge, or a wire with a hook bent on the end, pushed through from the top and pulled back until it catches. Write all eight down with the hole numbers. The scan suggests they vary between about 12 and 38 mm; that is expected.

Also note the thickness of the outer skin if you can see it at a hole (probably about 0.8 mm).

### 5. Send back
- Photo of the taped template on the hood, with A and B visible.
- The A–B, A–centre, B–centre distances.
- The eight depths.
- Anything that looked wrong.

That is the end of Round 1. The design will be updated with the real depths, and the two bolts that might need to be longer get decided.

---

## Round 2 — cut, make, print, fit

### Parts to have ready
Everything in [BOM.md](BOM.md). Nothing needs supports. The plate prints top face down (the curved side ends up on top), the cowl roof down. ASA wants a closed printer door, a hot bed, and a brim on the plate. If you use the AMS, the logo in the first three layers of the cowl is where the purple goes.

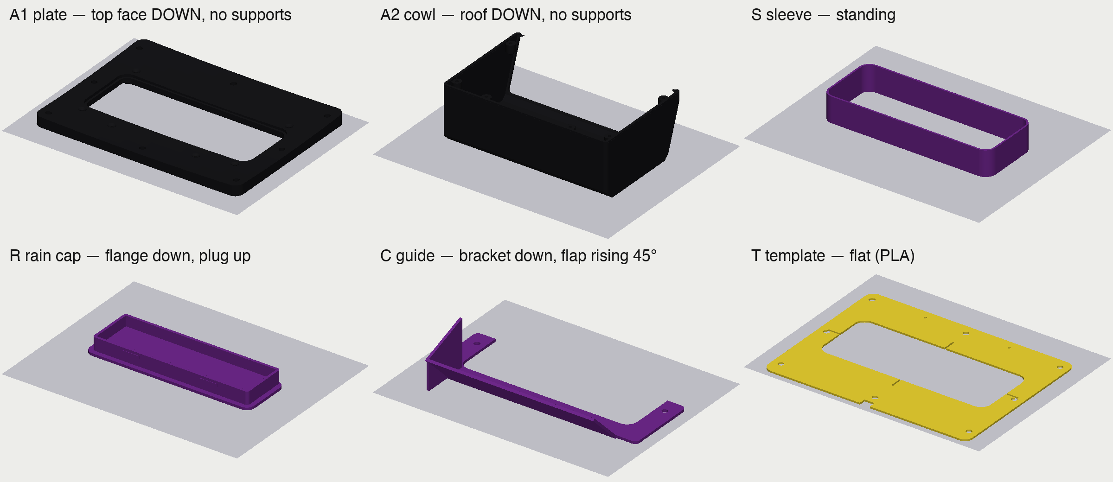
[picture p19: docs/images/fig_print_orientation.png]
Print orientations


### 6. Join the cowl to the plate (bench)
Set the plate on the bench **upside down**, curved side up. Drop the cowl onto it the right way round (logo reads from the front, raked mouth toward the FRONT notch side of the plate); the lip around the cowl's bottom edge sits in the groove in the plate. Hold them together and drive the six **M4 self-tapping screws** up through the countersunk holes in the plate into the bosses inside the cowl. Snug, not cranked; they only hold a plastic lid on. Turn the assembly over and check the cowl sits flush all round.

Exploded

### 7. Cut the opening
Mask the paint. From outside, drill a 3 mm hole at the template centre first and check the outline looks right against the hood from above. Then cut the outer skin to **199 x 75 mm with 12 mm radius corners**: a hole saw or step drill at the four corners, a jigsaw with a fine metal blade between them. Stay 1 mm inside the line and file to size. Cut the inner panel to the same size from below. Deburr everything and prime the bare metal.

### 8. Open the bolt holes
Outer skin: **6.5 mm**. Inner panel: **10.5 mm** (a step drill is easiest). The inner panel gets the bigger hole on purpose: a spacer tube passes through it and bears on the outer skin, so the inner panel is never squeezed.

### 9. Make the metal bits
Flat bar 25 x 3: two long pieces, 249 mm, each with three 6.5 mm holes. The easy way to mark them is to lay the template on the bar and mark through holes 1-7-2 for one strip and 5-8-6 for the other. Two short pieces, 110 mm, with one hole in the middle. Round the ends and deburr.

Tube Ø10: eight **limiters, 8.0 mm long** (they must all be the same length, square ends). Eight **spacers**, one per hole, each cut to that hole's measured depth minus 2.4 mm (that is minus the skin and a washer). Label them 1 to 8.

### 10. Bolt it on

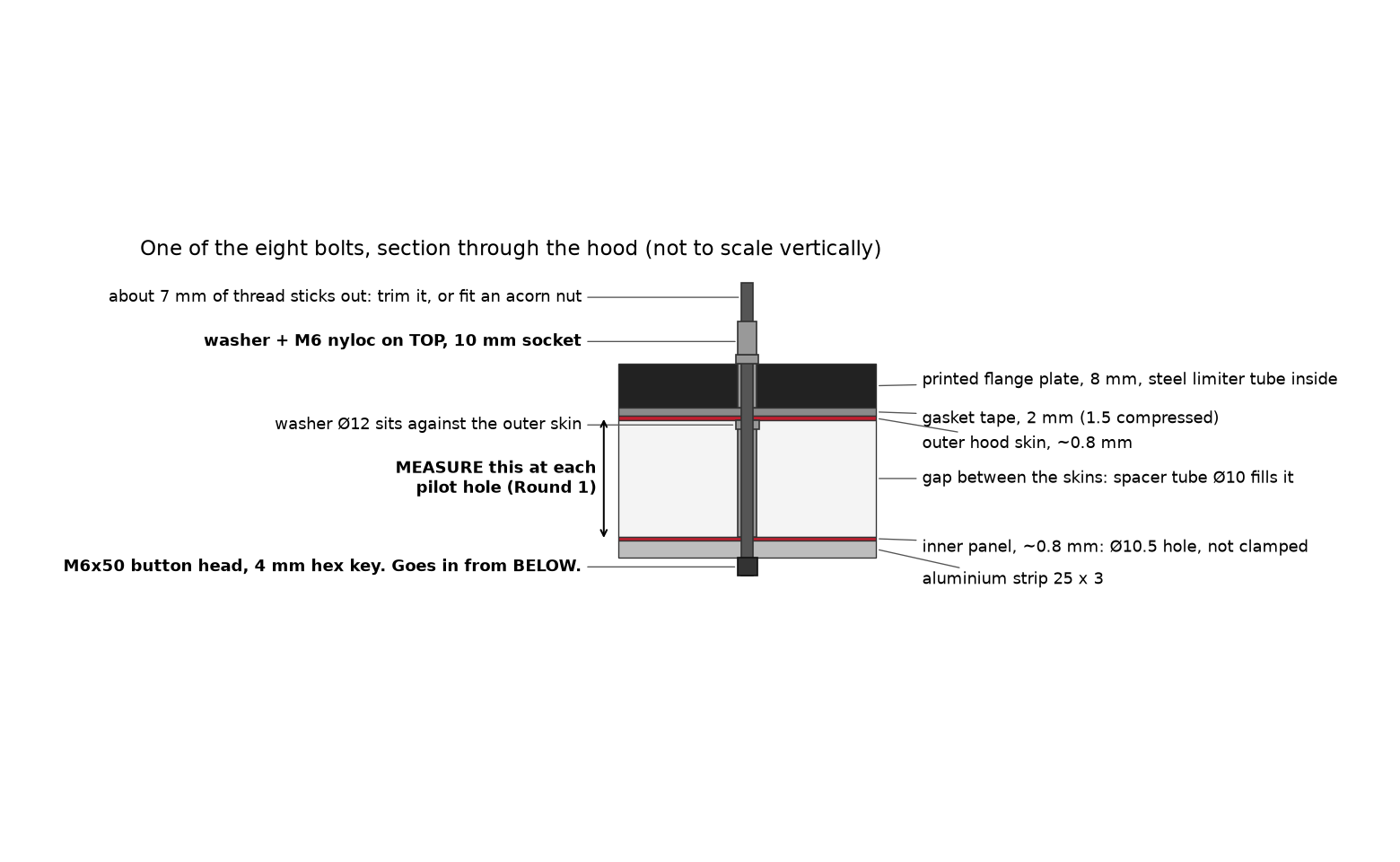
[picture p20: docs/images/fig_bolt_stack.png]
Bolt stack


1. Stick the foam gasket tape around the underside of the plate as one unbroken loop near the edge, and a second loop around the throat.
2. Push the eight limiter tubes into the plate holes. Set the assembly on the hood over the opening.
3. From below, for each hole: slide a washer onto the spacer tube, push the tube up through the big inner-panel hole until the washer touches the outer skin, hold a strip under it, and push an **M6x50 up from below** through strip, tube, skin and plate. On top: washer and nyloc, finger tight. Long strips front and rear, short strips on the two middle bolts.
4. Tighten all eight in a criss-cross, finishing at **5 to 6 N·m** with a 10 mm socket. The steel tubes take the load; you cannot crush the plastic.
5. Push the **sleeve** up from below into the throat until it seats. Run a bead of RTV where it passes the inner panel.
6. Try the **rain cap**: it pushes into the mouth and the lip sits against the raked face.
7. **Guide**: take the two middle bolts out, slide the bracket's arms between the strips and the bolt heads, put the bolts back and torque. Press a lump of modelling clay onto the flap tip, close the hood fully, open it and look at the clay: you want at least 25 mm to the cone and 15 mm to any hose or wire.
8. Trim the thread sticking up above the nuts (cover the paint), or fit acorn nuts over them.

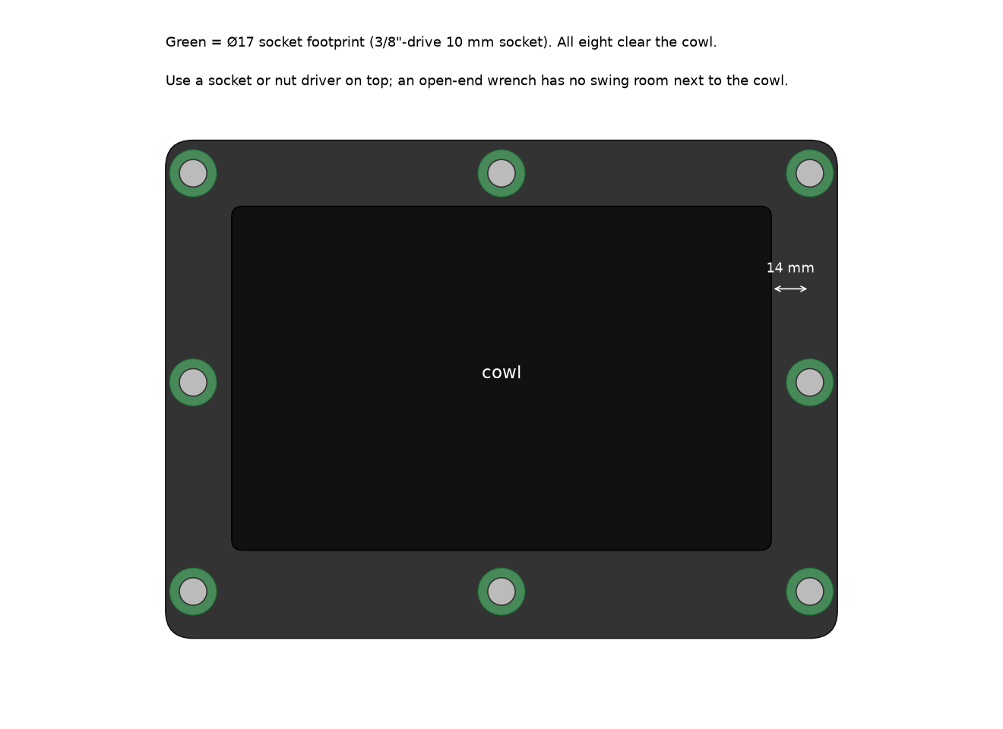
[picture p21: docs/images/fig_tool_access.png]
Tool access


### 11. Check it works
- Close the hood slowly three times, then normally. Nothing should touch.
- After a hot run: look for sag in the cowl, droop in the flap.
- Hose test with the cap off: water should run out of the mouth and drip off the flap in front of the cone, not onto it. Cap on: dry throat.
- Re-torque the eight nuts after the first session.

## If something does not fit
Every dimension is a parameter. Tell us what interfered and by how much, and a new part comes back the same day.

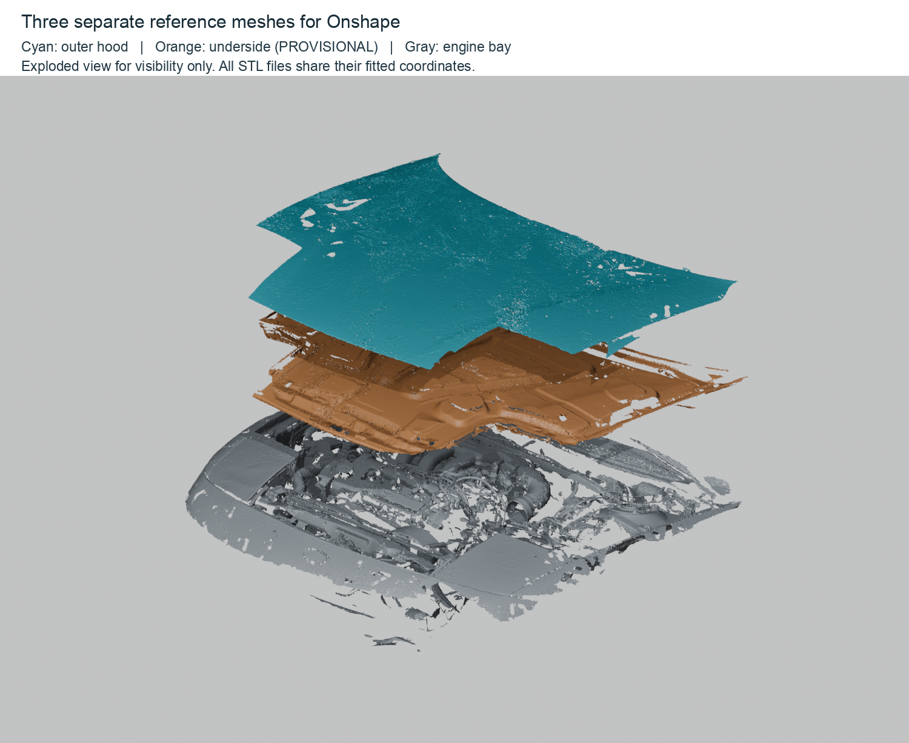
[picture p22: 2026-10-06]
reference/scan/13_labeled_assembly.png

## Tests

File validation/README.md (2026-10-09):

# Validation

`validation_report.md` is generated by `cad/validate.py` from the STLs in `stl/` and the scan meshes in `reference/scan/`. Summary of the current parts:

| Check | Result |
|---|---|
| Plate underside vs scanned hood skin | median gap 1.6 mm (gasket 1.5), p95 3.4 mm |
| Under-hood clearance to engine-bay scan, hood closed | sleeve 12 mm, guide 12 mm, bolt heads 11 mm, strips 11 mm |
| Guide flap to cone (placeholder from scan void and photo) | 54 mm |
| Inner-panel depth at the 8 bolt sites (provisional scan) | 12 to 38 mm; design value 21; measure at pilot holes |
| Mouth area | 103 cm² (smallest section) |
| Tool access | 10 mm socket clears the cowl at all 8 nuts by 3.5 mm or more; heads reachable with the hood open; M4 joint done on the bench |
| Printability | all parts watertight; no supports in the listed orientations (only 45° faces: boss cones, flap, countersinks) |
| Local mirror vs Onshape export | surfaces agree within 0.13 mm |

Not checked: hood-closing sweep, airflow, hot-soak strength, anything the scan does not contain (the cone, loose hoses and wiring).

`clearance_map_site.png` shows how much room there is between the closed hood and the engine around the opening, with the cone placeholder drawn in.

Re-run: `python3 cad/validate.py stl validation`

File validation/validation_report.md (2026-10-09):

# Validation report — Probe hood scoop

Site: scan X 110, Y -340, skin Z 104.2 (label-neighbourhood estimate). All clearances come from the scan meshes; the cone is a placeholder; the hood underside registration is PROVISIONAL.

## 1. Flange underside vs outer skin (scan)
- 12948 sampled points on the flange underside. Distance to the scanned skin: min 0.00, median 1.59, p95 3.46, max 6.60 mm. Design gasket gap is 1.5 mm, so a median near 1.5 with p95 under ~3 means the lofted underside tracks the real hood within scan noise.

## 2. Under-hood clearance to the engine-bay scan
| item | min clearance (mm) | where (scan XYZ) |
|---|---|---|
| throat sleeve | 12.1 | [199.0, -372.0, 70.0] |
| guide U-bracket + flap | 12.1 | [214.0, -353.0, 69.0] |
| bolt heads (head-down, under strips) | 10.5 | [217.0, -342.0, 67.0] |
| backing strips | 11.1 | [209.0, -383.0, 68.0] |

Anything under ~15 mm needs a physical check; the scan lacks the cone and may miss hoses/wiring. Hood closing sweep is not simulated.

## 3. Cone placeholder (D150, from scan void + photo; NOT scanned)
- guide U-bracket + flap: min gap 51.2 mm (positive = clear)
- throat sleeve: min gap 103.5 mm (positive = clear)

The brief's starting target is a 25–50 mm outlet-to-filter gap. Set the flap reach/angle after measuring the real cone.

## 4. Inner panel depth below the outer skin at each fastener (PROVISIONAL scan)
| location (local x,y) | depth: skin top → inner-panel underside (mm) | spacer tube = depth − 0.8 skin − 1.6 washer (mm) |
|---|---|---|
| bolt 1 (-112,-80) | 38.5 | 36.1 |
| bolt 2 (+112,-80) | 14.9 | 12.5 |
| bolt 3 (-112,-4) | 20.3 | 17.9 |
| bolt 4 (+112,-4) | 15.7 | 13.3 |
| bolt 5 (-112,+72) | 20.2 | 17.8 |
| bolt 6 (+112,+72) | 18.3 | 15.9 |
| bolt 7 (+0,-80) | 29.8 | 27.4 |
| bolt 8 (+0,+72) | 12.3 | 9.9 |

Design value is 21 mm. The tube passes through a Ø10.5 hole in the inner panel and bears on a washer against the outer skin, so the inner panel is never clamped; cut each tube to its own measured length after the pilot holes. Depths over ~34 mm exceed the M6x50; buy two M6x60 or move that bolt. The front row sits on the rib transition — check it first.

## 5. Flow areas (geometry only, no CFD)
- Mouth clear 186 x 55.5 R4 = **103.1 cm²** (smallest section; brief minimum 100–110, preferred 120–135).
- Throat (sleeve inside) 195 x 71 R10 = 137.6 cm². Hood cut with sleeve = 199 x 75 = 148.0 cm².
- Verdict: above the minimum, below the preferred band. If you want 120 cm² later, raise the roof to 76 (mouth 59.5) — one parameter.

## 6. Print orientation / overhang check (faces steeper than 45° facing down, excluding the bed face)
| part | orientation | overhang area cm² | % of surface | volume cm³ | est. g (ASA, 4 walls, ~40% infill) | bbox in print orientation |
|---|---|---|---|---|---|---|
| A1_flange_plate.stl | top face down (curved underside up) | 14.9 | 1.9 | 293.1 | 194 | [244.0, 181.0, 12.8] |
| A2_cowl.stl | roof down | 39.4 | 4.0 | 141.5 | 94 | [196.0, 125.0, 66.0] |
| R_rain_cap.stl | flange face down, plug up | 1.4 | 0.4 | 82.2 | 55 | [196.0, 60.5, 18.0] |
| S_throat_sleeve.stl | standing upright (as modelled) | 0.0 | 0.0 | 31.2 | 21 | [199.0, 75.0, 29.9] |
| C_guide_flap.stl | bracket face down, flap rising at 45° | 136.3 | 30.7 | 62.3 | 41 | [250.0, 121.0, 59.2] |
| T_fit_check_template.stl | flat (as modelled) | 0.0 | 0.0 | 57.6 | 38 | [244.0, 181.0, 2.0] |

All parts print support-free in the listed orientation; the only faces counted are the 45° boss cones and the 45° flap, which print cleanly.

## 7. Tool and hand access
- Nuts are on top of the flange. Nut centre to cowl wall: sides 14.0 mm, front 15 mm, rear 12 mm. A 3/8"-drive 10 mm socket (Ø17) has 5.5 / 6.5 / 3.5 mm of margin → **OK**. Use a socket or nut driver, not an open-end wrench (no swing room on the cowl side).
- Bolt heads are under the backing strips. With the hood open the underside is fully exposed, so a 4 mm hex key (button head) or 5 mm (cap head) reaches every head; the engine bay only matters with the hood closed.
- Sleeve, guide bracket and strips all go in from below with the hood open; the bezel and rain cap from the front. Nothing has to be reached through the mouth.

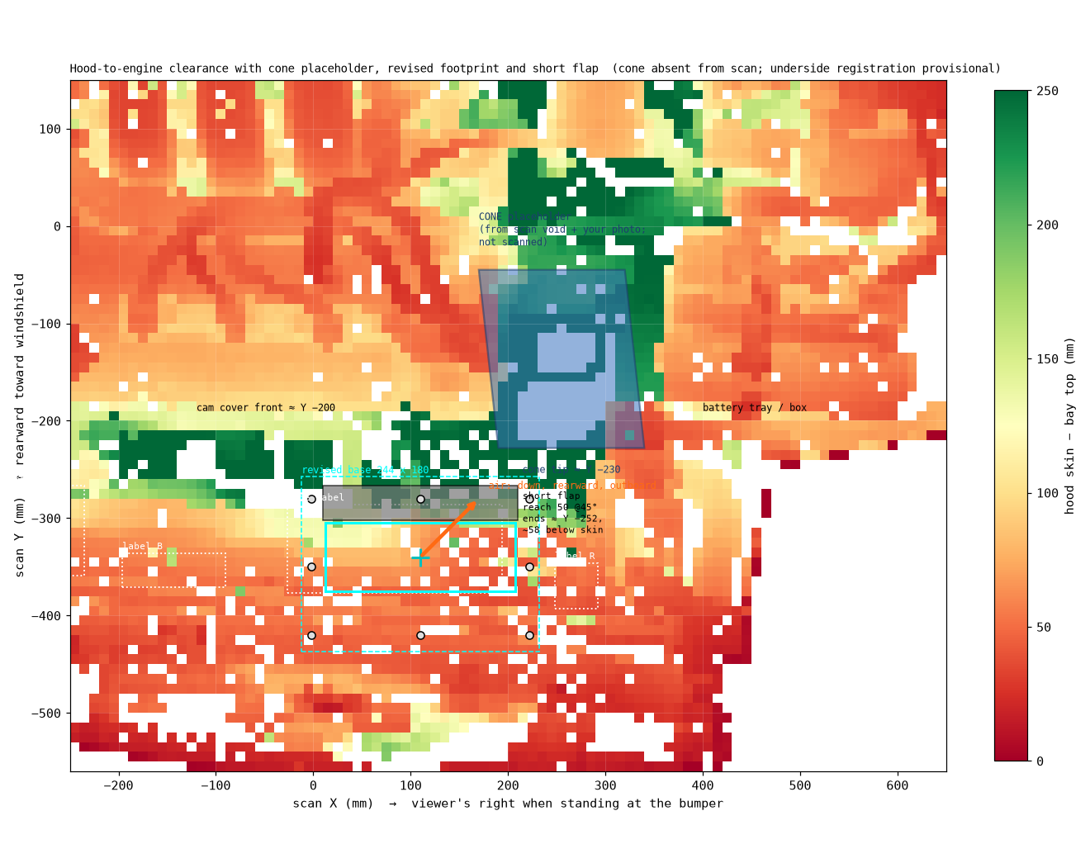
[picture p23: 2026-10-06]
validation/clearance_map_site.png

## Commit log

2026-10-06 Probe GT hood scoop: printable parts, build guide, BOM, validation, CAD sources
    [01_engine_bay_mm.stl, 02_hood_outer_mm.stl, 03_hood_underside_PROVISIONAL_mm.stl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]
2026-10-06 Bolt stack figure: separate the inner panel and strip labels
2026-10-06 Location figure: put the cone-filter box on the cone
2026-10-06 Sync Onshape: current FeatureScript, STEP export, assembly link
    [probe_hood_scoop_system.step, probe_hood_scoop_system_revF_onshape.step]
2026-10-06 Assembly script: insert scan composites by part ID
2026-10-09 Rev H: two-piece support-free body, raked mouth, M4 bench joint, AMS logo, decisions page
    [A1_flange_plate.stl, A2_cowl.stl, A_body.stl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]
2026-10-11 BOM: shopping checklist with sources
2026-10-12 Cowl screw bosses become full-height columns: no overhang when printed roof-down
2026-10-12 Add point-cloud check request for the plate site
2026-10-13 Guide: flap trimmed flush and fin extended to the bracket face so it prints flat
